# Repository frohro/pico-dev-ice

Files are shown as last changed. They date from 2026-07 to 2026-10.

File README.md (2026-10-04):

# <span style="text-transform: none;">The Pico Dev-iCE 📡</span>
**DSP Educational Vehicle & iCE40 Mixed-Signal Laboratory**

## 📌 Overview
The **Pico Dev-iCE** is a low-cost, high-performance "Lab-in-a-Box." It combines the high-speed programmable logic of a **Lattice iCE40UP5K FPGA** with the flexible C/MicroPython ecosystem of a **Raspberry Pi Pico (YD-RP2040 with 16MB Flash)**. 

Designed specifically as an educational platform, it abandons "black box" RF chips in favor of discrete, observable analog blocks. Students can physically probe the RF signal path, design their own LC filters on pluggable sandboxes, and write Verilog to perform Direct Digital Conversion (DDC), digital decimation, and hardware I2S audio routing.

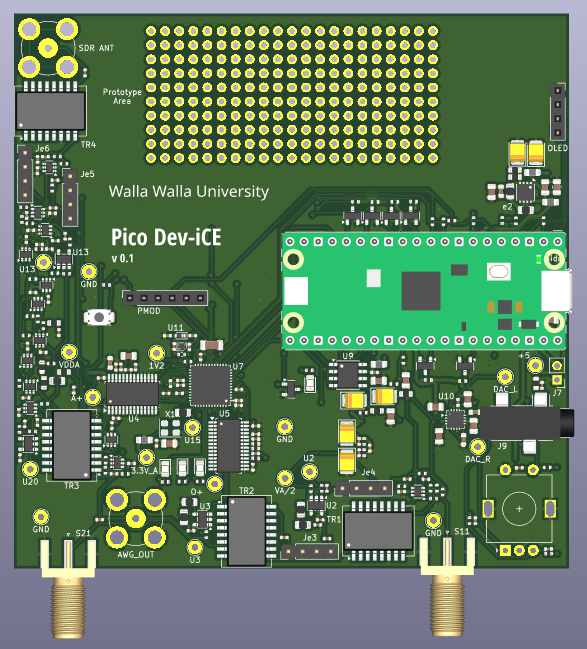
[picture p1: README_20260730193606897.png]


Here is a video of the SDR receiving on 20 meters.(https://youtu.be/qYo4EEl96wU).
## 🚀 Key Capabilities
* **HF Software Defined Radio (RX/TX):** Full-duplex DDC/DUC transceiver covering 0 - 15.36 MHz (1st Nyquist) with Super-Nyquist capabilities up to 30+ MHz.
* **Vector Network Analyzer (VNA):** Built-in Return Loss Bridge (RLB) for S11 (reflection) antenna tuning, and Port-to-Port S21 (transmission) filter characterization.
* **Arbitrary Waveform Generator (AWG):** Dedicated DC-coupled and AC-coupled SMA outputs for 30 MSPS generic signal generation.
* **Real-Time Spectrum Analyzer:** Visualize the entire 15 MHz HF spectrum simultaneously via FPGA-accelerated FFTs.
* **Standalone Operation:** Onboard Audio DAC/Headphone amp and rotary encoder support allows the board to operate as a standalone radio without a PC.

---

## 🧠 Hardware Architecture

### Processing Core
* **Microcontroller:** YD-RP2040 / Pico 2 socket. Handles AGC math, user interface, USB communications, and slow-state hardware toggles. The massive internal Flash (up to 16MB) stores the FPGA bitstream and programs the FPGA directly on every boot, eliminating the need for an external FPGA flash chip.
* **FPGA:** Lattice iCE40UP5K (SG48). Handles high-speed 30.72 MHz DSP, NCO generation, CIC decimation/interpolation, and I2S master clocking.
* **Control Bus:** The Pico uses its high-speed `SPI0` bus to dual-role: it blasts the bitstream into the FPGA's internal CRAM on boot, and then seamlessly transitions to sending runtime DSP commands to the user's Verilog over the exact same 4 wires.

### Clocking & DSP Math
* **Master Clock:** A clean 30.720 MHz CMOS oscillator drives the FPGA.
* **The Magic of 30.72 MHz:** The FPGA decimates the 30.72 MSPS ADC data by exactly $R=640$ to yield a mathematically perfect **48.000 kHz** baseband I/Q audio stream over I2S to the Pico. 
* **Process Gain:** The 640x decimation provides ~ 28 dB of digital processing gain, turning the raw 8-bit ADC into a highly sensitive 12.6-bit effective receiver!

### The Receive (RX) Path
* **Topology:** `SMA` ➔ `Ethernet Isolation/CMC` ➔ `Band Sandbox` ➔ `T/R Switch` ➔ `LNA 1` ➔ `PGA (5/10dB)` ➔ `LNA 2` ➔ `ADC`.
* **Amplifiers:** Uses discrete high-speed op-amps wired as AC-coupled inverting amplifiers. 
* **Programmable Gain:** A Digital Step Attenuator (DSA) built from CMOS switches and precision T-networks, providing 0 to 55 dB of gain control in 5 dB steps. LNA 1 and LNA 2 are both bypassable to prevent clipping on massive signals.
* **ADC (MS9280):** 8-bit, 32 MSPS. Driven by an RF balun into True Differential Mode with a 4.5V analog supply, yielding a massive 4.0V peak-to-peak input span for maximum dynamic range.

### The Transmit (TX) Path
* **Topology:** `DAC` ➔ `Passive I-V` ➔ `Ethernet Transformer` ➔ `TX Switch` ➔ `Recon Sandbox` ➔ `TX Op-Amp (+12dB)` ➔ `T/R Switch` ➔ `SMA`.
* **DAC (MS9708):** 8-bit, 32 MSPS Current-Steering DAC.
* Passive 50Ω resistors and an Ethernet transformer gracefully map the DAC's strict output compliance limits into a clean 1.0V p-p RF signal, which is then amplified to drive a 50-ohm antenna.

### Power Domains (Strict Isolation)
To achieve commercial-grade noise floors, the noisy Switch-Mode Power Supply (SMPS) of standard Picos is bypassed/isolated. 
* **`+4.5V AVDD`:** Clean LDO powering the RF op-amps, analog switches, and ADC/DAC analog cores.
* **`+3.3V Digital`:** LDO powering the FPGA I/O, Pico, and IC logic.
* **`+3.3V Clean`:** Ferrite bead + LC filtered rail strictly for the 30.72 MHz oscillator to eliminate phase-noise/jitter.

---

## 🎛️ Port & Jumper Reference

### Coaxial Connectors
1. **`SDR_ANT`(BNC):** Main Transceiver Port (Transformer isolated, AC-Coupled).
2. **`SII` (SMA):** Device Under Test port for S11/VSWR Antenna measurements. Connects to the internal Return Loss Bridge.
3. **`AWG_OUT` (BNC):** Direct DC-coupled output (0V to +4V) from the DAC. Perfect for baseband signal generation.
4. **`S21` (SMA):** AC-coupled output for S21 Filter sweeps and RF signal generation. Protects the op-amp from DC-shorted filters.

### Filter Sandboxes (Plug-and-Play)
The board features `IN-GND-GND-OUT` 0.1" sockets for inserting custom filter daughterboards. 
* **Band Sandbox:** Shared by both RX and TX (pre-T/R switch). Students calculate and test bandpass filters here.
* **TX Pre-Sandbox:** Placed before the TX amplifier. Used for mild Nyquist reconstruction filters or super-Nyquist image-selection filters.

---

## 🛠️ Software & HDL Notes

* **Level Shifters (Logic Inversion):** The 4.5V analog switches are controlled by 3.3V GPIOs via 2N7002 N-Channel MOSFETs. **Note:** This results in a logic inversion. Writing `0` to the pin in MicroPython = Switch HIGH (Max Gain / Default Path). Writing `1` = Switch LOW (Attenuated / VNA / TX Path).
* **FPGA Boot & SPI0 Bus:** 
    *   The external FPGA Flash chip was removed to simplify the architecture. The Pico boots the FPGA directly by blasting the bitstream into CRAM using its Hardware `SPI0` block. 
    *   Because the Pico drives the bus, the net names match the Pico's hardware roles: `SPI0_TX` (MOSI) is data entering the FPGA, and `SPI0_RX` (MISO) is data leaving the FPGA. 
    *   **Runtime:** Once booted, the Pico reuses the exact same `SPI0` bus and `ICE_SSN` Chip Select pin to send DSP commands to the user's Verilog.
* **ADC OTR:** The MS9280 "Out of Range" (Clipping) pin pulses for only 32ns. The FPGA catches this, stretches the pulse, and triggers a hardware interrupt on the Pico to engage the AGC.

The ten-week, verification-first HDL course sequence is documented in
[`DDC_SDR_Lab_Plan.md`](DDC_SDR_Lab_Plan.md).

---

## 📍 Hardware Pinout Reference

### 1. Microcontroller (Raspberry Pi Pico) Pinout
*This map defines the interface for the software team handling AGC, VNA sweeps, user interface, and I2S audio routing.*

| Pico GPIO | Net Name | Function | Direction | Notes |
| :--- | :--- | :--- | :--- | :--- |
| **GPIO 0** | `FPGA_INT` | FPGA Hardware Interrupt | Input | Catches stretched ADC Out-Of-Range (OTR) pulses |
| **GPIO 1** | `PMOD_3` | PMOD / GPIO Jump | I/O | Connected via series resistor R32 to PMOD_3 |
| **GPIO 2** | `SDA` | I2C Data | In/Out | I2C bus for the OLED Display |
| **GPIO 3** | `SCL` | I2C Clock | Output | I2C bus for the OLED Display |
| **GPIO 4** | `SPI0_RX` | SPI0 MISO | Input | Data entering Pico from FPGA (via series resistor R33) |
| **GPIO 5** | `ICE_SSN` | SPI0 CSn (FPGA CS) | Output | Hardware SPI0 Chip Select (Boot & Runtime) |
| **GPIO 6** | `SPI0_CLK` | SPI0 SCK | Output | SPI Clock for Boot and Runtime (via series resistor R34) |
| **GPIO 7** | `SPI0_TX` | SPI0 MOSI | Output | Data leaving Pico to FPGA (via series resistor R35) |
| **GPIO 8** | `PGA0` | 5 dB Attenuator | Output | Logic 1 = Attenuator Active (LOW at switch) |
| **GPIO 9** | `PGA1` | 10 dB Attenuator | Output | Logic 1 = Attenuator Active (LOW at switch) |
| **GPIO 10** | `PGA2` | LNA 2 Bypass | Output | Logic 1 = LNA Bypassed (LOW at switch) |
| **GPIO 11** | `PGA3` | LNA 1 Bypass | Output | Logic 1 = LNA Bypassed (LOW at switch) |
| **GPIO 12** | `BAND_SW` | Band Filter Sandbox | Output | Toggles sandbox selection switch |
| **GPIO 13** | `TX_DATA` | I2S TX Data | Output | Full-Duplex Baseband Audio TO the FPGA |
| **GPIO 14** | `RX_DATA` | I2S RX Data | Input | Full-Duplex Baseband Audio FROM the FPGA |
| **GPIO 15** | `BCK` | I2S Bit Clock | Input | Clocks generated by FPGA (I2S Master) |
| **GPIO 16** | `WS` | I2S Word Select (L/R) | Input | Clocks generated by FPGA (I2S Master) |
| **GPIO 17** | `AF_DAC_DATA` | Audio DAC Data | Output | I2S out to standalone headphone amp |
| **GPIO 18** | `AF_DAC_MCLK` | Audio DAC Master | Output | I2S out to standalone headphone amp |
| **GPIO 19** | `AF_DAC_SCLK` | Audio DAC Clock | Output | I2S out to standalone headphone amp |
| **GPIO 20** | `AF_DAC_LRCK` | Audio DAC L/R | Output | I2S out to standalone headphone amp |
| **GPIO 21** | `ICE_DONE` | FPGA Boot Status | Input | Goes HIGH when FPGA is running and lights White LED |
| **GPIO 22** | `~ICE_RST` | FPGA Reset | Output | Pull LOW to hold FPGA in reset |
| **GPIO 26** | `REF` | Front-End RF Mux | Output | **0 = SDR RF Antenna RX**, 1 = VNA Input |
| **GPIO 27** | *(Optional)* | PMOD / GPIO Jump | I/O | Jumper JP3 maps to PMOD_2 |
| **GPIO 28** | `~T/R` | Transmit/Receive Sw | Output | **1 = RX Mode** (Antenna -> LNA), 0 = TX Mode |

### 2. FPGA (Lattice iCE40UP5K-SG48) Pinout
*This map defines the interface for the digital design team writing Verilog and the `.pcf` constraints file.*

| Pin # | Lattice Name | Net Name | Function / Connection |
| :---: | :--- | :--- | :--- |
| **37** | `IOT_45a_G1` | `CLK` | **30.72 MHz Master Clock IN** (From Oscillator) |
| **23** | `IOT_37a` | `ADC_CLK` | ADC Clock OUT (To MS9280 via 22Ω resistor) |
| **6** | `IOB_13b` | `DAC_CLK` | DAC Clock OUT (To MS9708) |
| **25** | `IOT_36b` | `D0` | ADC Data Bit 0 (LSB) |
| **26** | `IOT_39a` | `D1` | ADC Data Bit 1 |
| **27** | `IOT_38b` | `D2` | ADC Data Bit 2 |
| **28** | `IOT_41a` | `D3` | ADC Data Bit 3 |
| **31** | `IOT_42b` | `D4` | ADC Data Bit 4 |
| **32** | `IOT_43a` | `D5` | ADC Data Bit 5 |
| **34** | `IOT_44b` | `D6` | ADC Data Bit 6 |
| **35** | `IOT_46b_G0` | `D7` | ADC Data Bit 7 (MSB) |
| **36** | `IOT_48b` | `OTR` | ADC Out of Range (Clipping Flag) |
| **4** | `IOB_8a` | `DB0` | DAC Data Bit 0 (LSB) |
| **3** | `IOB_9b` | `DB1` | DAC Data Bit 1 |
| **2** | `IOB_6a` | `DB2` | DAC Data Bit 2 |
| **48** | `IOB_4a` | `DB3` | DAC Data Bit 3 |
| **47** | `IOB_2a` | `DB4` | DAC Data Bit 4 |
| **46** | `IOB_0a` | `DB5` | DAC Data Bit 5 |
| **45** | `IOB_5b` | `DB6` | DAC Data Bit 6 |
| **44** | `IOB_3b_G6` | `DB7` | DAC Data Bit 7 (MSB) |
| **14** | `IOB_32a_SPI_SO` | `SPI0_RX` | SPI MISO (Data *to* Pico during runtime) |
| **17** | `IOB_33b_SPI_SI` | `SPI0_TX` | SPI MOSI (Data *from* Pico during runtime) |
| **15** | `IOB_34a_SPI_SCK`| `SPI0_CLK` | SPI Clock IN (From Pico GPIO 6) |
| **16** | `IOB_35b_SPI_SS` | `ICE_SSN` | SPI Chip Select IN (From Pico GPIO 5) |
| **12** | `IOB_22a` | `BCK` | I2S Bit Clock OUT (To Pico GPIO 15) |
| **9** | `IOB_16a` | `WS` | I2S Word Select OUT (To Pico GPIO 16) |
| **11** | `IOB_20a` | `RX_DATA` | I2S Data OUT (SDR audio to Pico GPIO 14) |
| **10** | `IOB_18a` | `TX_DATA` | I2S Data IN (Transmit audio from Pico GPIO 13) |
| **13** | `IOB_24a` | `FPGA_INT` | Hardware Interrupt OUT (To Pico GPIO 0) |
| **38** | `IOT_50b` | `ANG_0` | Rotary Encoder / Tuning Knob A |
| **42** | `IOT_51a` | `ANG_1` | Rotary Encoder / Tuning Knob B |
| **43** | `IOT_49a` | `ANG_2` | Rotary Encoder / Tuning Knob Switch |
| **21** | `IOB_23b` | `PMOD_0` | PMOD Header Pin 1 |
| **19** | `IOB_29b` | `PMOD_1` | PMOD Header Pin 2 |
| **18** | `IOB_31b` | `PMOD_2` | PMOD Header Pin 3 |
| **20** | `IOB_25b_G3` | `PMOD_3` | PMOD Header Pin 4 |
| **39** | `RGB0` | `RED` | Open-Drain LED Driver (Active-Low: 0=ON, pulses on ADC OTR clipping) |
| **40** | `RGB1` | `YELLOW` | Open-Drain LED Driver (Active-Low: 0=ON, pulses on SPI tuning activity) |
| **41** | `RGB2` | `GREEN` | Open-Drain LED Driver (Active-Low: 0=ON, steady ON when un-reset) |
| **7** | `CDONE` | `ICE_DONE` | *Hardware Boot / Status Out* |
| **8** | `~CRESET` | `~ICE_RST` | *Hardware Boot / Reset In* |

## Pico SDK Bring-Up

The SDK port is under `Software/pico-ice-sdk`. It uses the checked-in Pico SDK
(currently 2.2.0). The general SDK examples use the TinyUSB revision bundled by
that SDK. The DDC firmware below uses a newer TinyUSB checkout because it needs
the UAC1 descriptor definitions that are not present in the bundled revision.

The smallest board-specific firmware example programs the FPGA's volatile CRAM directly from the RP2040:

```sh
cmake -S Software/pico-ice-sdk/examples/rp2_dev_ice_blinky \
    -B Software/pico-ice-sdk/examples/rp2_dev_ice_blinky/build \
    -DPICO_BOARD=pico_dev_ice -DPICO_NO_PICOTOOL=1
cmake --build Software/pico-ice-sdk/examples/rp2_dev_ice_blinky/build
```

The generated UF2 is RP2040 firmware that contains the FPGA bitstream. The Dev-iCE has no external FPGA configuration flash, so the board port excludes the external-flash and TinyUF2 FPGA-storage paths. SPI0 GPIO 6 is the CRAM transfer clock and GPIO 7 carries configuration data; normal FPGA operation uses the separate external 30.720 MHz oscillator, not a Pico-generated clock on GPIO 27.

## DDC SDR Firmware

The first Dev-iCE SDR application is in
[`Software/ddc_sdr_firmware`](Software/ddc_sdr_firmware). It replaces the
earlier Si5351a, Tayloe detector, and PCM1808 path with FPGA-generated DDC I/Q data received as
PCM1808-compatible I2S. The Pico firmware:

* programs the FPGA's volatile CRAM over SPI0;
* reuses SPI0 for runtime frequency and sample-rate commands;
* captures FPGA I2S with DMA; and
* exposes stereo 24-bit UAC1 audio at 48 kHz and 96 kHz, CDC control, and a
    DFU interface.

The DDC application requires a TinyUSB checkout with both `src/tusb.h` and
`hw/bsp/rp2040`. A current checkout at `$HOME/tinyusb` is detected
automatically, or it can be selected explicitly:

```sh
cmake -S Software/ddc_sdr_firmware -B Software/ddc_sdr_firmware/build \
        -DPICO_TINYUSB_PATH="$HOME/tinyusb" \
        -DPICO_BOARD=pico_dev_ice \
        -DPICO_NO_PICOTOOL=1
cmake --build Software/ddc_sdr_firmware/build -j2
```

The Pico firmware keeps FPGA deployment easy to choose: `FPGA_BOOT_MODE=DFU`
waits for a development bitstream from `dfu-util`, while
`FPGA_BOOT_MODE=STORED` loads an image embedded in the Pico firmware at boot.
Two stored transceiver profiles can be included with
`FPGA_RX_BITSTREAM_BIN` and `FPGA_TX_BITSTREAM_BIN`, with
`FPGA_DEFAULT_IMAGE` selecting the boot profile and `FPGA,LOAD,RX` or
`FPGA,LOAD,TX` selecting one between sessions. The full commands and build
examples are in [`Software/ddc_sdr_firmware/README.md`](Software/ddc_sdr_firmware/README.md).

These profile loads are not a VNA sweep mechanism. A VNA needs a single
coherent FPGA design containing the stimulus, reference, receive, and
measurement paths for the complete sweep. Select a persistent VNA-capable
image before a measurement, or implement those paths in one integrated image;
do not reconfigure between sweep points.

For development, compile an FPGA bitstream with Yosys, nextpnr-ice40, and
icepack, then load it without reflashing the Pico:

```sh
python3 Software/ddc_sdr_firmware/tools/dfu_fpga.py /path/to/ddc_sdr.bin
```

Stop the SDR++ or Quisk audio stream before starting DFU. The helper prepares
the shared SPI0 bus, sends the packed bitstream through `dfu-util`, and lets the
Pico restore the runtime FPGA state afterward. Do not reset the Pico after a
DFU-only update: FPGA CRAM is volatile and a reset clears the loaded design.

For the complete pinout, SPI protocol, CDC commands, build options, and DFU
sequence, see [`Software/ddc_sdr_firmware/README.md`](Software/ddc_sdr_firmware/README.md).

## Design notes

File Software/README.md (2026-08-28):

# Pico Dev-iCE Software & DSP Architecture

This document provides a comprehensive technical reference for the **Pico Dev-iCE Software-Defined Radio (SDR)** system, detailing the mathematical foundations of the Digital Down-Conversion (DDC) pipeline, the Programmable Gain Amplifier (PGA) control and Automatic Gain Control (AGC) algorithms, the system block diagrams, and the software repository directory layout.

---

## Table of Contents
1. [System Architecture & Block Diagram](#1-system-architecture--block-diagram)
2. [Mathematical Foundations of the DSP Pipeline](#2-mathematical-foundations-of-the-dsp-pipeline)
   - [2.1 RF Sampling & Offset-Binary Conversion](#21-rf-sampling--offset-binary-conversion)
   - [2.2 DC Auto-Zero Offset Correction](#22-dc-auto-zero-offset-correction)
   - [2.3 Numerically Controlled Oscillator (NCO)](#23-numerically-controlled-oscillator-nco)
   - [2.4 Complex Quadrature Downconversion (Mixer)](#24-complex-quadrature-downconversion-mixer)
   - [2.5 Cascaded Integrator-Comb (CIC) Decimating Filter](#25-cascaded-integrator-comb-cic-decimating-filter)
   - [2.6 Output Scaling & Bit Growth Analysis](#26-output-scaling--bit-growth-analysis)
   - [2.7 Dual-Rate FIR Passband Droop Equalization](#27-dual-rate-fir-passband-droop-equalization)
   - [2.8 Dual-Rate I2S Baseband Transmission](#28-dual-rate-i2s-baseband-transmission)
3. [PGA Gain Control & AGC Algorithm](#3-pga-gain-control--agc-algorithm)
   - [3.1 Hardware PGA Architecture](#31-hardware-pga-architecture)
   - [3.2 Manual Gain Control & OpenHPSDR Protocol 1 Mapping](#32-manual-gain-control--openhpsdr-protocol-1-mapping)
   - [3.3 Fast-Attack / Timed-Decay Overload AGC](#33-fast-attack--timed-decay-overload-agc)
4. [Software Directory Overview](#4-software-directory-overview)
   - [4.1 ddc_sdr_firmware](#41-ddc_sdr_firmware)
   - [4.2 ddc_sdr_firmware_usb_working](#42-ddc_sdr_firmware_usb_working)
   - [4.3 Soapy-Dev-iCE](#43-soapy-dev-ice)
   - [4.4 Pico Dev-iCE MicroPython](#44-pico-dev-ice-micropython)
   - [4.5 pico-ice-sdk](#45-pico-ice-sdk)

---

## 1. System Architecture & Block Diagram

The Pico Dev-iCE SDR partitions signal processing between a high-speed **Lattice iCE40UP5K FPGA** (performing real-time Digital Down-Conversion, dual-rate CIC decimation, and FIR passband droop compensation at 30.72 MHz) and a **Raspberry Pi RP2040 / Pico W MCU** (handling DMA sample acquisition, USB Audio streaming, Wi-Fi OpenHPSDR Protocol 1 streaming, AGC supervision, and Command & Control).
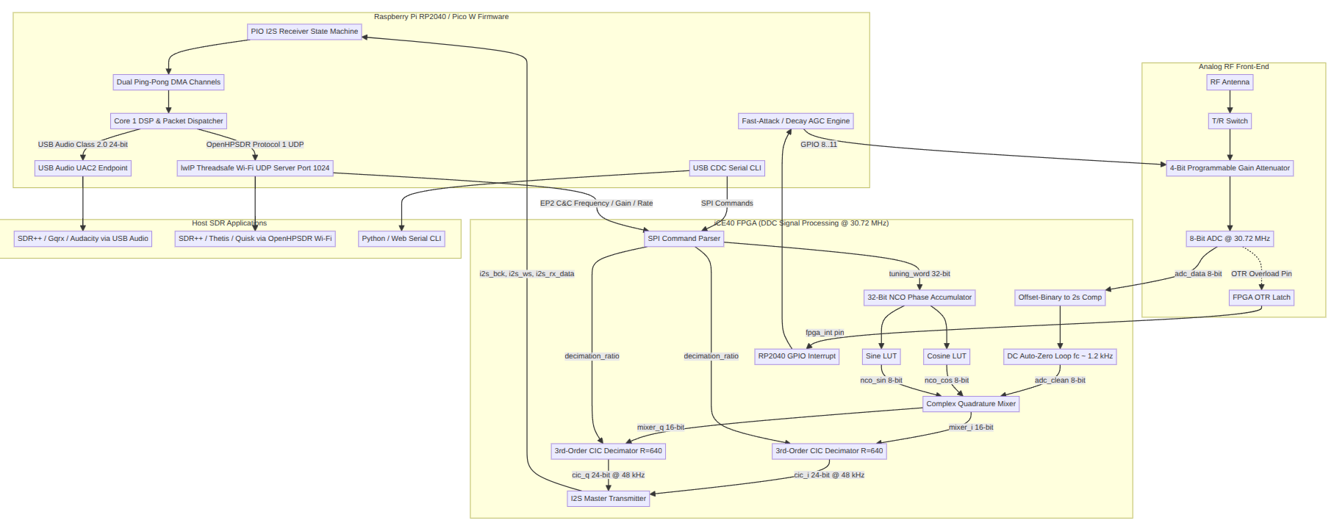
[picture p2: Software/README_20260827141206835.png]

```mermaid
graph TD
    subgraph Analog_RF_FrontEnd ["Analog RF Front-End"]
        ANT[RF Antenna] --> TR[T/R Switch]
        TR --> PGA[4-Bit Programmable Gain Attenuator]
        PGA --> ADC[8-Bit ADC @ 30.72 MHz]
        ADC -.->|OTR Overload Pin| FPGA_INT[FPGA OTR Latch]
    end

    subgraph FPGA_DSP ["iCE40 FPGA (DDC Signal Processing @ 30.72 MHz)"]
        ADC -->|adc_data 8-bit| O2C[Offset-Binary to 2s Comp]
        O2C --> DCZ[DC Auto-Zero Loop fc ~ 1.2 kHz]
        DCZ -->|adc_clean 8-bit| MIX[Complex Quadrature Mixer]
        
        NCO_GEN[32-Bit NCO Phase Accumulator] --> SIN_LUT[Sine LUT]
        NCO_GEN --> COS_LUT[Cosine LUT]
        COS_LUT -->|nco_cos 8-bit| MIX
        SIN_LUT -->|nco_sin 8-bit| MIX

        MIX -->|mixer_i 16-bit| CIC_I[Dual-Rate CIC Decimator R=640/320]
        MIX -->|mixer_q 16-bit| CIC_Q[Dual-Rate CIC Decimator R=640/320]

        CIC_I -->|cic_i 24-bit| FIR_I[5-Tap Symmetric FIR Compensator]
        CIC_Q -->|cic_q 24-bit| FIR_Q[5-Tap Symmetric FIR Compensator]

        FIR_I -->|audio_i 24-bit @ 48k/96k| I2S_TX[Dual-Rate I2S Master Transmitter]
        FIR_Q -->|audio_q 24-bit @ 48k/96k| I2S_TX
        
        SPI_SLV[SPI Command Parser] -->|tuning_word 32-bit| NCO_GEN
        SPI_SLV -->|CMD_SET_SAMPLE_RATE 0x02| CIC_I
        SPI_SLV -->|CMD_SET_SAMPLE_RATE 0x02| CIC_Q
        SPI_SLV -->|rate_select| I2S_TX
        FPGA_INT -->|fpga_int pin| MCU_INT[RP2040 GPIO Interrupt]
    end

    subgraph MCU_RP2040 ["Raspberry Pi RP2040 / Pico W Firmware"]
        I2S_TX -->|i2s_bck, i2s_ws, i2s_rx_data| PIO_RX[PIO I2S Receiver State Machine]
        PIO_RX --> DMA[Dual Ping-Pong DMA Channels]
        DMA --> CORE1[Core 1 DSP & Packet Dispatcher]
        
        CORE1 -->|USB Audio Class 2.0 24-bit| USB_EP[USB Audio UAC2 Endpoint]
        CORE1 -->|OpenHPSDR Protocol 1 UDP| WIFI_LWIP[lwIP Threadsafe Wi-Fi UDP Server Port 1024]
        
        AGC_CTRL[Fast-Attack / Decay AGC Engine] -->|GPIO 8..11| PGA
        MCU_INT --> AGC_CTRL
        CDC_CLI[USB CDC Serial CLI] -->|SPI Commands| SPI_SLV
        WIFI_LWIP -->|EP2 C&C Frequency / Gain / Rate| SPI_SLV
    end

    subgraph Host_Software ["Host SDR Applications"]
        USB_EP --> SDRPP_U[SDR++ / Gqrx / Audacity via USB Audio]
        WIFI_LWIP --> SDRPP_W[SDR++ / Thetis / Quisk via OpenHPSDR Wi-Fi]
        CDC_CLI --> SERIAL_APP[Python / Web Serial CLI]
    end
```

---

## 2. Mathematical Foundations of the DSP Pipeline

### 2.1 RF Sampling & Offset-Binary Conversion
The analog RF input is digitized by an 8-bit Flash ADC clocked at $f_s = 30.720\text{ MHz}$. The ADC produces unsigned offset-binary samples $x_{raw}[n] \in [0, 255]$.

To convert unsigned offset-binary to 8-bit signed two’s complement $x_{signed}[n] \in [-128, 127]$, the MSB is inverted:

$$x_{signed}[n] = x_{raw}[n] - 128 = \left( \sim x_{raw}[7] \right) \mathbin{\Vert} x_{raw}[6:0]$$

---

### 2.2 DC Auto-Zero Offset Correction
ADC hardware imperfection and local board coupling introduce a static DC offset bias $V_{DC}$. If passed uncorrected into the mixer, $V_{DC} \cdot \cos(\omega_{lo} n)$ produces a massive spurious tone directly at the tuned center frequency ($0\text{ Hz}$ IF).

An autonomous digital tracking loop dynamically integrates and subtracts this DC bias before mixing:

$$\text{dc\_acc}[n] = \text{dc\_acc}[n-1] + x_{signed}[n] - \text{sign\_ext}\left(\text{dc\_acc}[n-1][23:12]\right)$$

$$x_{clean}[n] = \text{saturate}_{[-128, 127]}\left( x_{signed}[n] - \text{dc\_acc}[n][23:12] \right)$$

This creates a high-pass notch with a cutoff frequency:

$$f_{c} \approx \frac{f_s}{2^{12} \cdot 2\pi} = \frac{30.720\text{ MHz}}{4096 \cdot 2\pi} \approx 1.193\text{ kHz}$$

This eliminates center-frequency LO carrier spikes without degrading passband signals.

---

### 2.3 Numerically Controlled Oscillator (NCO)
The NCO implements a 32-bit phase accumulator clocked at $f_{clk} = 30.720\text{ MHz}$. For a target RF center frequency $f_{tune}$, the RP2040 calculates the 32-bit integer tuning word $M$:

$$M = \operatorname{round}\left( \frac{f_{tune}}{f_{clk}} \cdot 2^{32} \right) = \operatorname{round}\left( \frac{f_{tune}}{30{,}720{,}000} \cdot 4{,}294{,}967{,}296 \right)$$

The phase accumulator updates on every clock cycle:

$$\theta[n] = \left( \theta[n-1] + M \right) \pmod{2^{32}}$$

The frequency resolution $\Delta f$ is:

$$\Delta f = \frac{f_{clk}}{2^{32}} = \frac{30.720\text{ MHz}}{4{,}294{,}967{,}296} \approx 0.007153\text{ Hz}$$

The top 8 bits $\theta[n][31:24]$ index 256-word quarter-wave trigonometric lookup tables to yield 8-bit signed quadrature LO reference signals:

$$I_{lo}[n] = \cos\left( \frac{2\pi \cdot \theta[n]}{2^{32}} \right), \quad Q_{lo}[n] = \sin\left( \frac{2\pi \cdot \theta[n]}{2^{32}} \right)$$

---

### 2.4 Complex Quadrature Downconversion (Mixer)
The clean real RF input signal $x_{clean}[n]$ is multiplied by the quadrature LO signals $I_{lo}[n]$ and $Q_{lo}[n]$ to produce in-phase ($I$) and quadrature ($Q$) products:

$$I_{mix}[n] = x_{clean}[n] \cdot I_{lo}[n] = x_{clean}[n] \cos(\omega_{lo} n)$$

$$Q_{mix}[n] = x_{clean}[n] \cdot Q_{lo}[n] = x_{clean}[n] \sin(\omega_{lo} n)$$

For an arbitrary narrowband input signal $x(t) = A(t) \cos(\omega_{rf} t + \phi(t))$ where $\omega_{rf} = \omega_{lo} + \omega_{if}$:

$$I_{mix}(t) = \frac{A(t)}{2}\left[ \cos(\omega_{if} t + \phi(t)) + \cos((2\omega_{lo} + \omega_{if})t + \phi(t)) \right]$$

$$Q_{mix}(t) = \frac{A(t)}{2}\left[ -\sin(\omega_{if} t + \phi(t)) + \sin((2\omega_{lo} + \omega_{if})t + \phi(t)) \right]$$

The complex analytic signal at the mixer output is:

$$z_{mix}(t) = I_{mix}(t) + j Q_{mix}(t) = \frac{A(t)}{2} e^{-j(\omega_{if} t + \phi(t))} + \frac{A(t)}{2} e^{j((2\omega_{lo} + \omega_{if})t + \phi(t))}$$

The high-frequency $2\omega_{lo}$ sum term is removed by the subsequent decimation filter, isolating the baseband spectrum $e^{-j\omega_{if} t}$.

---

### 2.5 Cascaded Integrator-Comb (CIC) Decimating Filter
Decimation and low-pass anti-aliasing filtering are implemented using a **3-Stage Cascaded Integrator-Comb (CIC) filter** (Hogenauer, 1981) with differential delay $M=1$ and decimation ratio $R = 640$ (for $48\text{ kHz}$) or $R = 320$ (for $96\text{ kHz}$).

The system transfer function in the $z$-domain is:

$$H(z) = \left( \frac{1 - z^{-R M}}{1 - z^{-1}} \right)^N = \left( \sum_{k=0}^{R M - 1} z^{-k} \right)^N, \quad N=3, \; M=1$$

The discrete-time frequency response is:

$$|H(f)| = \left| \frac{\sin\left(\pi \frac{R M f}{f_s}\right)}{\sin\left(\pi \frac{f}{f_s}\right)} \right|^N$$

#### Filter Structure:
1. **3 Integrator Stages** clocked at full ADC rate $f_s = 30.72\text{ MHz}$:
   $$I_1[n] = I_1[n-1] + x[n]$$
   $$I_2[n] = I_2[n-1] + I_1[n]$$
   $$I_3[n] = I_3[n-1] + I_2[n]$$
2. **Decimator $\downarrow R$**: Samples $I_3[n]$ every $R=640$ clocks ($f_{out} = 48\text{ kHz}$).
3. **3 Comb Stages** clocked at decimated rate $f_{out}$:
   $$C_1[m] = I_3[m] - I_3[m-1]$$
   $$C_2[m] = C_1[m] - C_1[m-1]$$
   $$C_3[m] = C_2[m] - C_2[m-1]$$

---

### 2.6 Output Scaling & Bit Growth Analysis

#### DC Gain:
$$G = (R \cdot M)^N = 640^3 = 262{,}144{,}000 \approx 2^{27.966}$$

#### Maximum Bit Growth ($B_{growth}$):
$$B_{growth} = \lceil N \log_2(R \cdot M) \rceil = \lceil 3 \log_2(640) \rceil = \lceil 27.966 \rceil = 28\text{ bits}$$

#### Register Sizing:
With a 16-bit signed mixer input ($B_{in} = 16$), the internal accumulator width required to prevent mathematical overflow (by two’s complement wrap-around invariance) is:

$$B_{internal} = B_{in} + B_{growth} = 16 + 28 = 44\text{ bits}$$

#### Dynamic Range Slicing:
- Theoretical peak signed input: $|x_{in}| = 127 \times 128 = 16{,}256 \approx 2^{13.989}$
- Peak theoretical output: $16{,}256 \times 640^3 = 4.262 \times 10^{12} \approx 2^{41.95}$
- Bits $[43:42]$ are redundant sign-extension bits.
- By extracting bits **$[41:18]$** (24 bits total), the filter yields maximum 24-bit dynamic range with **$+12\text{ dB}$ higher sensitivity** while mathematically guaranteeing zero clipping on full-scale sinusoidal RF inputs.

---

### 2.7 Dual-Rate FIR Passband Droop Equalization

While the 3-stage CIC decimator provides high stopband attenuation, its passband exhibits severe $\text{sinc}^3$ droop:
- At $48\text{ kHz}$ ($R=640$), the response droops by **$-7.92\text{ dB}$ at $20\text{ kHz}$** ($0.416 F_s$).
- At $96\text{ kHz}$ ($R=320$), the response droops by **$-7.92\text{ dB}$ at $40\text{ kHz}$** ($0.416 F_s$).

Because normalized frequency $\omega = 2\pi f / F_s$ is identical at both sample rates ($F_s \cdot R = F_{\text{clk}} = 30.72\text{ MHz}$), the exact same FIR compensator flattens both 48 kHz and 96 kHz rates.

#### Minimalist 5-Tap Folded FIR Architecture:
A 5-tap symmetric linear-phase FIR filter ($h_0, h_1, h_2, h_1, h_0$) flattens the response to **$\pm 0.48\text{ dB}$ ($0.96\text{ dB}$ total ripple $\le 1.0\text{ dB}$)**:

$$H_{\text{FIR}}(z) = h_0 + h_1 z^{-1} + h_2 z^{-2} + h_1 z^{-3} + h_0 z^{-4}$$

#### Signed 16-Bit Q2.14 Fixed-Point Sizing:
- $h_0 = h_4 = +0.100302 \times 16384 \approx \mathbf{+1643}$ (`16'sh066B`)
- $h_1 = h_3 = -0.389698 \times 16384 \approx \mathbf{-6385}$ (`16'shE70F`)
- $h_2 = +1.578857 \times 16384 \approx \mathbf{+25868}$ (`16'sh650C`) (Center tap)
- $\sum h_i = 1643 + 1643 - 6385 - 6385 + 25868 = \mathbf{16384} = 2^{14} \implies \mathbf{1.000000}$ **Exact DC Gain**.

#### Dual-Rate Gain Slicing:
- **48 kHz Mode ($R=640$):** Slices bits `[41:18]` (DC gain $= 640^3 / 2^{18} = 1000$).
- **96 kHz Mode ($R=320$):** Slices bits `[38:15]` (DC gain $= 320^3 / 2^{15} = 1000$).
- Dynamic 3-bit downward shift equalizes output volume across sample rate changes with zero multiplier logic.

---

### 2.8 Dual-Rate I2S Baseband Transmission
The compensated 24-bit $I$ and $Q$ samples are transmitted over an I2S serial link in standard Philips framing:
- **48 kHz Mode:** Bit Clock (`i2s_bck`) $= 3.072\text{ MHz}$ ($64 \times 48\text{ kHz}$), Word Select (`i2s_ws`) $= 48.0\text{ kHz}$.
- **96 kHz Mode:** Bit Clock (`i2s_bck`) $= 6.144\text{ MHz}$ ($64 \times 96\text{ kHz}$), Word Select (`i2s_ws`) $= 96.0\text{ kHz}$.
  - $\text{WS} = 0$ (Low): Left Channel = $I$ (In-phase sample)
  - $\text{WS} = 1$ (High): Right Channel = $Q$ (Quadrature sample)
- **Data (`i2s_rx_data`)**: 24-bit signed MSB-first, left-aligned in a 32-bit frame.

The RP2040 PIO state machine acts as an I2S slave, capturing 32 bits into the RX FIFO on each half-period of WS and populating memory buffers with alternating $(I, Q)$ pairs.

---

## 3. PGA Gain Control & AGC Algorithm

### 3.1 Hardware PGA Architecture
The analog front-end includes a 4-bit digitally controlled Programmable Gain Attenuator/Amplifier driven by RP2040 GPIOs $8, 9, 10, 11$ (`DDC_PGA_GPIO_BASE = 8`):

$$\text{PGA Code} \in [0x0, 0xF] \quad (0 \dots 15)$$

| PGA Code | Binary (`GPIO[11:8]`) | Nominal Attenuation | Front-End Net Gain | Mode / Typical Use |
|:---:|:---:|:---:|:---:|:---|
| **0x0** | `0000` | $0\text{ dB}$ | $+40\text{ dB}$ | Maximum Sensitivity / Weak Signal DX |
| **0x1** | `0001` | $-1\text{ dB}$ | $+39\text{ dB}$ | AGC Stage 1 Overload Cut |
| **0x2** | `0010` | $-2\text{ dB}$ | $+38\text{ dB}$ | Fine Manual Step |
| **0x3** | `0011` | $-3\text{ dB}$ | $+37\text{ dB}$ | AGC Stage 2 Overload Cut |
| $\dots$ | $\dots$ | $\dots$ | $\dots$ | Linear $1\text{ dB}$ steps |
| **0xF** | `1111` | $-15\text{ dB}$ | $+25\text{ dB}$ | AGC Maximum Overload Protection / Local Signals |

---

### 3.2 Manual Gain Control & OpenHPSDR Protocol 1 Mapping

Manual gain can be adjusted via CDC CLI or SDR software:
1. **CDC Serial CLI**:
   ```text
   PGA,<0..15>    # Sets attenuation code directly (0 = Max gain, 15 = Min gain)
   ```
2. **OpenHPSDR Protocol 1 / SDR++ Slider Mapping**:
   SDR++ presents an `LNA Gain` slider from $0\text{ dB}$ to $60\text{ dB}$ via Hermes-Lite Register `0x0A` (`HL_REG_RX_LNA`). The firmware maps this continuous slider to the discrete 4-bit hardware attenuation codes:

   $$\text{PGA Code} = 15 - \left\lfloor \frac{\text{Gain}_{SDR++} \times 15}{60} \right\rfloor$$

   - $\text{Gain}_{SDR++} = 60\text{ dB} \implies \text{PGA Code } 0$ (Max gain $+40\text{ dB}$)
   - $\text{Gain}_{SDR++} = 0\text{ dB} \implies \text{PGA Code } 15$ (Max attenuation / $+25\text{ dB}$)

---

### 3.3 Fast-Attack / Timed-Decay Overload AGC

When powerful out-of-band or in-band transmitters saturate the 8-bit ADC, the hardware ADC Out-Of-Range (`adc_otr`) pin fires. The FPGA catches this event, stretches the pulse, and asserts `fpga_int` to the RP2040.

#### AGC State Machine:
```mermaid
stateDiagram-v2
    [*] --> STATE_0dB : System Boot / Target Gain

    STATE_0dB --> STATE_1dB : OTR Interrupt (Fast Attack)
    STATE_1dB --> STATE_3dB : OTR Interrupt (Fast Attack)
    STATE_3dB --> STATE_15dB : OTR Interrupt (Fast Attack)

    STATE_15dB --> STATE_3dB : Quiet Timer > 2000 ms (Decay)
    STATE_3dB --> STATE_1dB : Quiet Timer > 2000 ms (Decay)
    STATE_1dB --> STATE_0dB : Quiet Timer > 2000 ms (Decay)
```

1. **Fast Attack (< 10 µs)**:
   When `fpga_int` triggers an interrupt:
   $$\text{Code}_{next} = \operatorname{StepUp}(\text{Code}_{current}): \quad 0\text{x0} \to 0\text{x1} \to 0\text{x3} \to 0\text{xF}$$
   The attenuator immediately steps to the next safe level, and an SPI command `DDC_FPGA_CMD_CLEAR_OTR` (0x04) clears the FPGA OTR latch.

2. **Hold & Timed Decay ($T_{decay} = 2000\text{ ms}$)**:
   - While `fpga_int` remains active or triggers repeatedly, the quiet timer resets to 0.
   - When the RF overload ceases, the system begins a $2000\text{ ms}$ quiet timer.
   - After $2000\text{ ms}$ with zero OTR pulses, the gain recovers by one step:
     $$\text{Code}_{prev} = \operatorname{StepDown}(\text{Code}_{current}): \quad 0\text{xF} \to 0\text{x3} \to 0\text{x1} \to 0\text{x0}$$
   - This prevents rapid gain pumping / flutter during intermittent high-signal transmissions.

---

## 4. Software Directory Overview

Below is the directory structure of the `Software/` folder and the purpose of each component:

```
Software/
├── README.md                    # DSP mathematics, PGA control, and architecture documentation (this file)
├── ddc_sdr_firmware/            # Primary active RP2040/Pico W production firmware
├── ddc_sdr_firmware_usb_working/ # Historical baseline USB-only firmware snapshot
├── Soapy-Dev-iCE/               # SoapySDR hardware driver module for SDR++/Gqrx
├── Pico Dev-iCE MicroPython/     # MicroPython runtime & hardware peripheral bindings
└── pico-ice-sdk/                # Low-level FPGA flashing & hardware abstraction library
```

---

### 4.1 `ddc_sdr_firmware`
**Active Production Firmware for RP2040 and Pico W.**
- **Dual-Path Streaming**:
  - **USB Audio Class 2.0 (UAC2)**: Isochronous 24-bit stereo audio streaming at 48/96 kHz.
  - **Wi-Fi OpenHPSDR Protocol 1**: Hermes SDR transceiver emulation over threadsafe background lwIP UDP on port 1024.
- **Hardware Bridges**:
  - **PIO I2S Driver (`i2s_rx.pio`)**: Non-blocking DMA-driven stereo receiver.
  - **FPGA CRAM DFU Loader**: Direct flashing and reprogramming of the iCE40 FPGA bitstream across boot and runtime.
  - **SPI Runtime Control**: High-speed frequency tuning, decimation rate switching, and OTR clearing.
- **Overload AGC Engine**: Multi-level fast-attack attenuator stepping with 2-second decay.
- **Full Duplex CDC Serial Interface**: CLI for frequency control, PGA setting, Wi-Fi configuration (`WIFI`, `SCAN`), and system status.

---

### 4.2 `ddc_sdr_firmware_usb_working`
**Reference USB Baseline Firmware.**
- Standalone snapshot of the firmware prior to Wi-Fi integration.
- Useful for minimal-footprint USB deployments or as a test golden reference.

---

### 4.3 `Soapy-Dev-iCE`
**SoapySDR Plugin for Native SDR Ecosystem Integration.**
- C++ hardware module implementing the `SoapySDR::Device` API.
- Enables native plug-and-play support for:
  - **SDR++** (via `soapy_source`)
  - **Gqrx**
  - **CubicSDR**
  - **GNU Radio** (via `gr-soapy` blocks)
- Exposes named gain elements (`PGA`, $0 \dots 15\text{ dB}$), hardware AGC switches, custom sample rates, and streaming channels.

---

### 4.4 `Pico Dev-iCE MicroPython`
**MicroPython Port for Interactive Experimentation.**
- MicroPython firmware build targeting the Pico Dev-iCE platform.
- Provides interactive Python REPL bindings to:
  - Load FPGA bitstreams from flash or filesystem.
  - Configure SPI/I2C registers dynamically.
  - Test custom DSP scripts and control GPIO pins interactively.

---

### 4.5 `pico-ice-sdk`
**Low-Level FPGA & Hardware Abstraction SDK.**
- Underlying C library providing:
  - iCE40 CRAM programming algorithms.
  - SPI flash pass-through programming.
  - Clock generation and RP2040-iCE40 pin mapping definitions.

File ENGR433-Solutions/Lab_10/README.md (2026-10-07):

# Lab 10 Solution: Automatic Gain Control

This solution implements the Pico-side AGC contract for the verified FPGA OTR
interrupt. It uses the existing C firmware rather than a blocking script:

- `agc_control.h` contains the host-testable AGC state machine.
- `main.c` keeps the GPIO interrupt callback short by setting a pending flag.
- The foreground loop advances the PGA state and sends the clear-OTR command.
- A nonblocking millisecond timer decays gain after 2 seconds of quiet.
- Runtime FPGA SPI is explicitly configured to 10 MHz.

The only automatic PGA sequence is:

```text
0x0 -> 0x1 -> 0x3 -> 0xF
```

Each OTR event advances one state and sends exactly:

```text
D5 01 04 04 01 00 00 00
```

At `0xF`, further OTR events remain saturated. When `FPGA_INT` is low for
2,000 ms, the state steps backward through `0x3`, `0x1`, and `0x0`. The timer
is restarted by a new OTR event and never blocks USB, audio, or CDC handling.

## Host tests

Run the AGC state-machine test:

```sh
gcc -std=c11 -Wall -Wextra -Werror \
  -I Software/ddc_sdr_firmware \
  -o /tmp/test_agc_control \
  Software/ddc_sdr_firmware/tools/test_agc_control.c
/tmp/test_agc_control
```

Run the protocol tests, including the exact clear-OTR frame:

```sh
python3 -m unittest \
  Software/ddc_sdr_firmware/tools/test_ddc_protocol.py
```

## Pico firmware build

### Build the Lab 10 FPGA TX image

From the repository root, build the Philips-I2S TX bitstream with:

```sh
ENGR433-Solutions/Lab_10/build_tx.sh
```

The default output directory is `ENGR433-Solutions/Lab_10/build-tx/`. The
script produces `lab10_tx_top.asc`, `lab10_tx_top.bin`, and the nextpnr timing
report. The packed `.bin` can be embedded in the Pico firmware build.

The generated image uses the following contract:

- BCK: 3.072 MHz at 48 kHz, or 6.144 MHz at 96 kHz.
- WS: 48 kHz or 96 kHz, with 32-bit left and right slots.
- WS changes on the rising edge sampling the previous slot's final bit.
- Data changes on BCK falling edges and is sampled on rising edges.
- 24-bit I/Q samples occupy bits `[31:8]`; bits `[7:0]` are zero.

### Build the USB-working Pico firmware with the TX image

After building the FPGA image, embed it in the USB-working firmware:

```sh
FPGA_TX_BITSTREAM_BIN="$PWD/ENGR433-Solutions/Lab_10/build-tx/lab10_tx_top.bin" \
FPGA_DEFAULT_IMAGE=TX \
  Software/ddc_sdr_firmware_usb_working/build.sh
```

The resulting UF2 is
`Software/ddc_sdr_firmware_usb_working/build/ddc_sdr.uf2`. Flash this UF2 to
the Pico and use the firmware's stored-image or DFU workflow to load the
matching FPGA image.

The checked-in SDK build can be used without hardware:

```sh
cmake --build Software/ddc_sdr_firmware/build-current-validation -j2
```

Or configure a fresh build as described in
`Software/ddc_sdr_firmware/README.md`. The resulting firmware includes the
nonblocking AGC loop and the 10 MHz runtime SPI setting.

## Hardware acceptance

1. Load the Lab 09 FPGA bitstream and the rebuilt Pico firmware.
2. Confirm the initial PGA code is `0x0`.
3. Assert `FPGA_INT` and confirm the code advances to `0x1`, then the FPGA OTR
   latch clears through the 8-byte SPI command.
4. Repeat until `0xF`; confirm additional OTR events do not wrap the state.
5. Keep `FPGA_INT` low for at least 2 seconds and confirm one-step decay.
6. Confirm USB audio and CDC command handling continue during the decay wait.

Live RF reception is optional hardware evidence. The host AGC and protocol
regressions are the required reproducible proof when no board or antenna is
available.

## Persistent VNA prototype

The directory also contains a carrier-only VNA image. Unlike the transceiver
profiles, this image remains loaded for the complete measurement sweep:

- `vna_top.sv` generates a single DAC carrier from a shared phase accumulator;
- `vna_correlator.sv` multiplies the ADC stream by the same sine/cosine
  references and accumulates a 1024-sample complex snapshot;
- `vna_spi_slave.sv` controls frequency/acquisition and reads the snapshot;
- `vna.pcf` preserves the production SG48 pin contract; and
- `vna_top_tb.sv` verifies coherent carrier feedback and SPI readback.

Build and pack it from the Lab 10 directory:

```sh
cd ENGR433-Solutions/Lab_10
iverilog -g2012 -s vna_top_tb -o /tmp/vna_top_tb.vvp \
    vna_top.sv vna_nco.sv vna_correlator.sv vna_spi_slave.sv vna_top_tb.sv
vvp /tmp/vna_top_tb.vvp
yosys -p 'read_verilog -sv vna_top.sv vna_nco.sv vna_correlator.sv vna_spi_slave.sv; synth_ice40 -top vna_top -json vna_top.json'
nextpnr-ice40 --up5k --package sg48 --freq 30.72 --top vna_top \
    --pcf vna.pcf --json vna_top.json --asc vna_top.asc
icepack vna_top.asc vna_top.bin
```

The measured route closes at 39.56 MHz on the 30.72 MHz system clock, using
551 of 5280 logic cells and one 4 Kbit block RAM. The raw I and Q results are
signed 32-bit correlation sums; a host should divide by the window length and
form DUT/reference complex ratios for magnitude and phase.

The VNA SPI additions retain the existing 8-byte command frame:

| Command | Value | Meaning |
| ---: | ---: | --- |
| `01` | FCW | Set the carrier frequency control word. |
| `05` | bit 0 | Clear the previous result and start a 1024-sample window. |
| `06` | `0..3` | Select the following read register: I, Q, status, or FCW. |

After a read-select command, assert CS for a separate four-byte SPI read. The
FPGA shifts the selected register most-significant bit first. `FPGA_INT` stays
high when the window is complete and returns low on the next clear command.
The Pico's GPIO26 `REF` control remains an external analog-switch control; the
FPGA does not drive it. A sweep should acquire a reference window, switch the
analog path, acquire the DUT window, and compute the complex ratio without
reconfiguring the FPGA.

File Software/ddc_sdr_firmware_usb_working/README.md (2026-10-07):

# Dev-iCE DDC SDR firmware

This application is the Dev-iCE successor to the earlier Si5351a/Tayloe/
PCM1808 implementation. The FPGA replaces the Si5351a LO, Tayloe detector, and PCM1808 audio ADC path. It
receives the FPGA's I/Q stream as PCM1808-compatible I2S and exposes the same
UAC1 stereo 24-bit capture format to SDR++ or Quisk.

## Dev-iCE Pico pins

| Signal | GPIO | Direction | Notes |
| --- | ---: | --- | --- |
| FPGA SPI0 MISO | 4 | Pico input | Runtime telemetry / SPI readback |
| FPGA SPI0 CS | 5 | Pico output | Shared CS for boot CRAM and runtime SPI |
| FPGA SPI0 SCK | 6 | Pico output | 10 MHz runtime SPI clock |
| FPGA SPI0 MOSI | 7 | Pico output | Runtime command frames to FPGA |
| FPGA I2S RX_DATA | 14 | Pico input | Baseband SDR I/Q audio from FPGA (Pin 11) |
| FPGA I2S BCK | 15 | Pico input | 3.072 MHz Bit Clock from FPGA (Pin 12) |
| FPGA I2S WS | 16 | Pico input | 48 kHz Word Select / LRCLK from FPGA (Pin 9) |
| FPGA I2S TX_DATA | 13 | Pico output | Transmit audio to FPGA (Pin 10) |
| FPGA interrupt | 0 | Pico input | Active-high OTR clipping notification |
| PGA control mask | 8..11 | Pico outputs | PGA0..PGA3 digital step attenuators |
| FPGA CDONE | 21 | Pico input | HIGH when FPGA CRAM boot is complete |
| FPGA CRESET | 22 | Pico output | Active-low FPGA hardware reset |
| REF Multiplexer | 26 | Pico output | **0 = SDR RF Antenna RX**, 1 = VNA Input |
| T/R Switch | 28 | Pico output | **1 = RX Mode**, 0 = TX Mode |
| Onboard Pico LED | 25 | Pico output | Toggles on FREQ and RATE tuning activity |
| 30.720 MHz clock | FPGA pin 37 | External oscillator | Master DSP clock reference |

The FPGA is the I2S master. The firmware supports 48 kHz (and 96 kHz)
UAC1 streaming, with standard Philips I2S framing, two channels (Left = I, Right = Q),
24 valid bits, and little-endian three-byte (`S24_3LE`) USB samples.

### I2S edge contract

The FPGA changes `WS` on the BCK rising edge that samples the previous
channel's final bit. It presents the new channel's MSB on the following BCK
falling edge; the Pico PIO samples that MSB on the next BCK rising edge. This
is the standard Philips one-bit WS-to-data delay. Each slot has 32 BCK bits,
with the 24-bit sample in bits `[31:8]` and zero padding in bits `[7:0]`.

## FPGA SPI protocol

Runtime SPI uses the same CS as CRAM configuration, GPIO 5. The Pico sends
this versioned frame after configuration:

```text
D5 01 command 04 value[31:0] little-endian
```

Commands are:

| Command | Value |
| ---: | --- |
| `01` | Set center frequency; value is a 32-bit FCW |
| `02` | Set output sample rate, 48000 or 96000 |
| `03` | Reserved for status reads |
| `04` | Clear the FPGA's sticky OTR event when value bit 0 is set |

The four PGA GPIOs form a hardware control mask: `PGA0` is the least-
significant bit and `PGA3` is the most-significant bit. This is not a linear
attenuation number. The verified gain states are:

| Mask | Hardware action | Nominal gain |
| ---: | --- | ---: |
| `0x0` | All MOSFETs off; straight path | `+40 dB` |
| `0x1` | 5 dB pad engaged | `+35 dB` |
| `0x3` | 5 dB and 10 dB pads engaged | `+25 dB` |
| `0xF` | All pads engaged; both LNAs bypassed | `-15 dB` |

The automatic overload path uses only the monotonic, verified sequence
`0x0 -> 0x1 -> 0x3 -> 0xF`. It starts at `0x0`, advances after each FPGA
OTR interrupt, and remains at `0xF` after the final step. Other masks remain
available for manual calibration, but are not selected automatically until
their gain has been measured.

The FPGA latches an OTR event, holds `fpga_int` high, and keeps it high
until it receives the `DDC_FPGA_CMD_CLEAR_OTR` command.

## CDC Serial Command Reference

The USB CDC interface (`/dev/ttyACM0`) supports interactive terminals (`picocom`, `minicom`, PuTTY)
with support for both `\r` (CR) and `\n` (LF) line endings, backspace (`0x08` / `0x7F`), and Ctrl+C (`0x03`).

| Command | Response | Description |
| :--- | :--- | :--- |
| `VER` | `VER,DDC SDR 0.1` / `OK` | Reports firmware version |
| `MODE` | `MODE,DDC` / `OK` | Reports SDR architecture mode (`DDC`) |
| `XTAL` | `XTAL,30720000` / `OK` | Reports master clock frequency in Hz |
| `FPGA,STATUS` | `FPGA,RX` / `OK` | Reports currently active FPGA image (`RX`, `TX`, or `DFU`) |
| `FPGA,LOAD,RX` | `FPGA,RX` / `OK` | Reconfigures FPGA CRAM with stored RX image |
| `FPGA,LOAD,TX` | `FPGA,TX` / `OK` | Reconfigures FPGA CRAM with stored TX image |
| `FREQ,<hz>` | `<hz>` / `OK` | Sets NCO tuning frequency in Hz (calculates 32-bit FCW) |
| `RATE,<hz>` | `RATE,<hz> OK` | Sets baseband audio sample rate in Hz (e.g. 48000) |
| `REF` | `REF,<0\|1>` / `OK` | Queries front-end RF multiplexer (`0` = SDR RF RX, `1` = VNA) |
| `REF,<0\|1>` | `REF,<0\|1>` / `OK` | Sets front-end RF multiplexer (`0` = SDR RF RX, `1` = VNA) |
| `PGA` | `PGA,<code>` / `OK` | Queries current PGA digital attenuator code (`0` = max $+40\text{ dB}$ gain) |
| `PGA,<code>` | `PGA,<code>` / `OK` | Sets PGA digital attenuator code (`0..15`) |
| `DEBUG` | `DEBUG: ready=...` / `OK` | Reports real-time DMA, I2S toggle counts, and GPIO states |
| `BOOTSEL` | `REBOOTING_BOOTSEL` | Soft-reboots the RP2040 into USB BOOTSEL flash mode |
| `HELP` / `?` | Command list / `OK` | Lists all available interactive CDC commands |

## Build

The firmware CMake project requires both the Raspberry Pi Pico SDK and the
Dev-iCE SDK integration. Set `PICO_ICE_SDK_PATH` to a checkout containing
`cmake/preinit_pico_ice_sdk.cmake`; set `PICO_SDK_PATH` if the Pico SDK is not
under that Dev-iCE checkout. The checked-in `build.sh` also accepts
`FPGA_RX_BITSTREAM_BIN`, `FPGA_TX_BITSTREAM_BIN`, and `FPGA_DEFAULT_IMAGE`.

For example, to build the USB firmware with the Lab 10 TX image selected at
boot:

```sh
PICO_ICE_SDK_PATH=/path/to/pico-ice-sdk \
FPGA_TX_BITSTREAM_BIN="$PWD/ENGR433-Solutions/Lab_10/build-tx/lab10_tx_top.bin" \
FPGA_DEFAULT_IMAGE=TX \
Software/ddc_sdr_firmware_usb_working/build.sh
```

The resulting board image is `Software/ddc_sdr_firmware_usb_working/build/ddc_sdr.uf2`.

Use the checked-in Pico SDK through the SDK port. Without a bitstream, the
firmware builds as a USB/DFU development image and waits for FPGA CRAM to be
loaded:

```sh
cmake -S Software/ddc_sdr_firmware -B Software/ddc_sdr_firmware/build \
    -DPICO_BOARD=pico_dev_ice -DPICO_NO_PICOTOOL=1
cmake --build Software/ddc_sdr_firmware/build -j2
```

For a production UF2 that configures the FPGA at every Pico boot, pass the
packed `icepack` output. The legacy `FPGA_BITSTREAM_BIN` variable is treated as
the stored RX image:

```sh
cmake -S Software/ddc_sdr_firmware -B Software/ddc_sdr_firmware/build-embedded \
    -DPICO_BOARD=pico_dev_ice -DPICO_NO_PICOTOOL=1 \
    -DFPGA_BOOT_MODE=STORED \
    -DFPGA_BITSTREAM_BIN=/path/to/ddc_sdr_rx.bin
cmake --build Software/ddc_sdr_firmware/build-embedded -j2
```

To store separate RX and TX images in the Pico firmware and boot into TX by
default, use:

```sh
cmake -S Software/ddc_sdr_firmware -B Software/ddc_sdr_firmware/build-stored \
    -DPICO_BOARD=pico_dev_ice -DPICO_NO_PICOTOOL=1 \
    -DFPGA_BOOT_MODE=STORED -DFPGA_DEFAULT_IMAGE=TX \
    -DFPGA_RX_BITSTREAM_BIN=/path/to/ddc_sdr_rx.bin \
    -DFPGA_TX_BITSTREAM_BIN=/path/to/lab10_tx.bin
cmake --build Software/ddc_sdr_firmware/build-stored -j2
```

`FPGA_BOOT_MODE=DFU` builds the development behavior: the Pico does not load
an image at reset and waits for `dfu-util`. `FPGA_BOOT_MODE=STORED` loads the
selected embedded image at every reset. `FPGA_DEFAULT_IMAGE` chooses RX or TX
when both images are present. The stored images are generated as separate C
arrays, so the same firmware can switch between them without reflashing the
Pico.

The `.uf2` flashes the RP2040. Dev-iCE has no FPGA configuration flash, so
FPGA CRAM is volatile and must be loaded again after reset or power loss.

While the firmware is running, the CDC control port accepts:

```text
FPGA,STATUS
FPGA,LOAD,RX
FPGA,LOAD,TX
```

`FPGA,LOAD,RX` and `FPGA,LOAD,TX` stop audio DMA, force GPIO28 high for
receive, release runtime SPI, reload the selected stored CRAM image, restore
the sample-rate and audio streams, and then allow the normal TX start path to
assert GPIO28 low. A missing image returns an error. `FPGA,STATUS` reports the
active image or `DFU`. The existing `DFU,PREPARE` and `dfu-util` workflow is
unchanged and remains useful for development images that are not embedded.

These are deployment and transceiver-profile choices. Use DFU while developing
or testing a new image, and use STORED when the Pico should boot a known image
from its own flash. If both stored images are embedded, RX and TX can be
selected at boot or between transceiver sessions with the `FPGA_DEFAULT_IMAGE`
setting and the `FPGA,LOAD,*` commands.

Do not use RX/TX CRAM switching as the ordinary VNA mode switch. A VNA sweep
needs its stimulus, reference, receive channel, and measurement processing to
remain clock-coherent for the entire sweep. VNA support therefore needs one
persistent VNA-capable FPGA design, either as its own stored image selected
before the measurement or as part of an integrated design; reconfiguration is
only a between-session operation.

## Development bitstream update

Stop or close the SDR++/Quisk audio stream before updating. Then run:

```sh
python3 Software/ddc_sdr_firmware/tools/dfu_fpga.py /path/to/ddc_sdr.bin
```

The helper sends `DFU,PREPARE`, which stops I2S/DMA and releases runtime SPI,
then invokes:

```sh
dfu-util -d 1209:b1c0 -a 0 -D /path/to/ddc_sdr.bin
```

The SDK's DFU callback streams the raw packed bitstream into FPGA CRAM and
checks CDONE. The Pico remains running; after a successful transfer it
reinitializes runtime SPI, restores the selected rate, and restarts I2S. The
helper deliberately does not pass `-R`, because a reset would clear volatile
CRAM and would also discard a bitstream that was only loaded through DFU.

The SDK also prepares automatically when the first DFU block arrives, so
`--skip-prepare` is available for manual testing:

```sh
python3 Software/ddc_sdr_firmware/tools/dfu_fpga.py --skip-prepare /path/to/ddc_sdr.bin
```

## Current gateware dependency

This directory defines the Pico-side contract but does not invent the DDC HDL
or its `.pcf`. Add the FPGA top level and Dev-iCE constraints separately, then
synthesize with `yosys`, place and route with `nextpnr-ice40`, pack with
`icepack`, and pass the resulting `.bin` to the build or DFU helper.

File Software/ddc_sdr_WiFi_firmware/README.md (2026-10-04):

# Dev-iCE DDC SDR Wi-Fi Firmware (OpenHPSDR Protocol 1)

This application runs on the **Raspberry Pi Pico W** on the Dev-iCE board. It interfaces with the iCE40 FPGA digital down-converter (DDC), receives 24-bit stereo I/Q samples over I2S via PIO, and streams them wirelessly over Wi-Fi using the standard **OpenHPSDR Protocol 1 (UDP port 1024)**.

All radio tuning, sample rate switching, and step-attenuator gain control are handled natively via OpenHPSDR Protocol 1 Command & Control (C&C) packets. All USB protocols (CDC and UAC1) have been removed, eliminating resource contention and timing conflicts.

## Compatible SDR Software

The firmware identifies as an **OpenHPSDR Hermes** device and works seamlessly with:
- **SDR++** (Select source: *Hermes*)
- **Quisk** (OpenHPSDR / Hermes hardware driver)
- **PowerSDR / Thetis**
- **SparkSDR**
- **linHPSDR**

## Dev-iCE Pico W Hardware Pinout

| Signal | GPIO | Direction | Notes |
| --- | ---: | --- | --- |
| FPGA SPI0 MISO | 4 | Pico input | Runtime SPI readback |
| FPGA SPI0 CS | 5 | Pico output | Shared CS for boot CRAM and runtime SPI |
| FPGA SPI0 SCK | 6 | Pico output | 10 MHz runtime SPI clock |
| FPGA SPI0 MOSI | 7 | Pico output | Runtime command frames to FPGA |
| FPGA I2S RX_DATA | 14 | Pico input | Baseband SDR I/Q audio from FPGA (Pin 11) |
| FPGA I2S BCK | 15 | Pico input | 3.072 MHz Bit Clock from FPGA (Pin 12) |
| FPGA I2S WS | 16 | Pico input | 48 kHz / 96 kHz Word Select from FPGA (Pin 9) |
| FPGA interrupt | 0 | Pico input | Active-high OTR clipping notification |
| PGA control mask | 8..11 | Pico outputs | PGA0..PGA3 digital step attenuators |
| FPGA CDONE | 21 | Pico input | HIGH when FPGA CRAM boot is complete |
| FPGA CRESET | 22 | Pico output | Active-low FPGA hardware reset |
| REF Multiplexer | 26 | Pico output | **0 = SDR RF Antenna RX**, 1 = VNA Input |
| T/R Switch | 28 | Pico output | **1 = RX Mode**, 0 = TX Mode |
| 30.720 MHz clock | FPGA pin 37 | External oscillator | Master DSP clock reference |

The FPGA is the I2S master. The firmware supports **48 kHz** and **96 kHz** sample rates, with Philips I2S framing, two channels (Left = I, Right = Q), 24 valid bits, and packages them into standard 1032-byte OpenHPSDR Protocol 1 EP6 packets (126 stereo samples / 252 words per packet).

## Automatic Gain Control (AGC) & Step Attenuators

The four PGA GPIOs (8..11) control the RF front-end step attenuators:
- `0x0`: Straight path, max gain (+40 dB)
- `0x1`: 5 dB pad engaged (+35 dB)
- `0x3`: 5 dB and 10 dB pads engaged (+25 dB)
- `0xF`: All pads engaged (-15 dB)

When an ADC overload occurs, the FPGA triggers an interrupt on GPIO 0. The firmware steps down the gain and clears the OTR condition. If the signal remains below threshold, the AGC decays back towards max sensitivity.

## Building for Pico W

Run the build script:

```bash
cd Software/ddc_sdr_WiFi_firmware
bash build_picow.sh
```

This compiles the firmware and embeds the DDC FPGA bitstream (`bitstreams/ddc_sdr_rx.bin`). The resulting binary is generated at:
```text
Software/ddc_sdr_WiFi_firmware/build-picow/ddc_sdr.uf2
```

## Flashing the Pico W

1. Put the Raspberry Pi Pico W in BOOTSEL mode: hold the BOOTSEL button while plugging the USB cable into your computer.
2. The `RPI-RP2` mass storage drive will appear.
3. Copy the firmware UF2:
   ```bash
   cp build-picow/ddc_sdr.uf2 /media/$USER/RPI-RP2/
   ```
4. The Pico W will reboot automatically, program the FPGA CRAM from flash, and connect to Wi-Fi.

## Wi-Fi Configuration

Settings are configured in [`wifi_config.h`](wifi_config.h):
- Primary SSID: `Frohne-Shop-2.4GHz`
- Secondary SSID: `Frohne-2.4GHz`
- Fallback Static IP: `192.168.1.191` (used if DHCP lease times out)
- Subnet Gateway: `192.168.1.1` | Netmask: `255.255.255.0`

## Pico W Status LED

The onboard Wi-Fi LED indicates connection and streaming state:

| Blink Pattern | Rate | Meaning |
| :--- | :--- | :--- |
| **Solid ON** | Constant | **Active SDR Streaming**: SDR client is actively receiving I/Q data. |
| **Steady Heartbeat** | 1 Hz | **Wi-Fi Connected (`CYW43_LINK_UP`)**: Listening for OpenHPSDR discovery. |
| **Medium Blink** | 2 Hz | **Associating / Acquiring IP** (`CYW43_LINK_JOIN` / `NO_IP`). |
| **Slow Blink** | 0.5 Hz | **Scanning / Reconnecting** (`CYW43_LINK_DOWN`). |

## Diagnostic & Verification Tools

### 1. Unified OpenHPSDR Test Suite
To verify network discovery, frequency tuning, streaming continuity, packet arrival delta, and I/Q balance:
```bash
python3 test_openhpsdr.py
```

### 2. Stream & FFT Spectrum Verification
To capture live packets and analyze the RF spectrum:
```bash
python3 test_openhpsdr_stream.py 192.168.1.191
```

### 3. Comprehensive Protocol 1 Compliance Test
```bash
python3 test_pico_w_openhpsdr.py --ip 192.168.1.191 --seconds 5.0
```

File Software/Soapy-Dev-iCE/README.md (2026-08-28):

# SoapySDR Driver for Pico-Dev-iCE DDC SDR & WWU 2026 SDR

A native [SoapySDR](https://github.com/pothosware/SoapySDR) module and hardware driver for the **Pico-Dev-iCE DDC SDR** (RP2040 + iCE40UP5K FPGA Software Defined Radio board) and the **WWU 2026 SDR** board.

This driver exposes the board as a standard SoapySDR receiver device, making it compatible with SDR software such as **SDR++**, **GQRX**, **GNU Radio**, and **CubicSDR**.

---

## Hardware Architecture & How It Works

```
                       ┌────────────────────────────────────────┐
                       │          Pico-Dev-iCE Board            │
                       │                                        │
[ Antenna ] ──> [ Front End / PGA ] <── [ MS9280 High-Speed ADC ]
                        │                         │             │
                    RF Signal                     │ 30.72 MSPS  │
                        ▼                         ▼             │
                [ iCE40UP5K FPGA ] ── NCO / Mixer / CIC DDC     │
                        │                                       │
                     I2S I/Q (24-bit stereo)                    │
                        ▼                                       │
                 [ RP2040 MCU ]                                 │
                        │                                       │
                        └────────────┬────────────┘             │
                                     │ USB                      │
                       ┌─────────────┴────────────┐             │
                       │  USB Audio   │  USB CDC  │             │
                       └──────┬───────┴─────┬─────┘             │
                              │             │                   │
══════════════════════════════╪═════════════╪═══════════════════╪══════════════════
 HOST COMPUTER                │             │
                              ▼             ▼
                       [ miniaudio ]   [ SerialPort ]
                        (Direct ALSA)   (115200 baud)
                              │             │
                              └──────┬──────┘
                                     ▼
                              [ Soapy2026SDR ]
                                     │
                                     ▼
                              [ SDR++ / GQRX ]
```

### 1. Control Protocol (USB CDC Serial)
* **Discovery:** Scans available serial ports for USB Vendor/Product IDs `0x1209:0xB1C0` (Pico-Dev-iCE DDC SDR) as well as `0xCAFE:0x4011` / `0xCAFE:0x4010` (WWU 2026 SDR).
* **Direct NCO Frequency Tuning (DDC):** When tuning frequency, the driver sends `FREQ,<hz>\r\n`. The RP2040 firmware computes the 32-bit frequency tuning word (FCW) and programs the FPGA NCO over SPI.
* **Dual Sample Rate (48 kHz / 96 kHz):** Supports dynamic switching between 48,000 Hz and 96,000 Hz via `RATE,<hz>\r\n`.
* **PGA Gain Control:** Digital step attenuator codes (0x0 = +40 dB, 0x1 = +35 dB, 0x3 = +25 dB, 0xF = -15 dB) via `PGA,<code>\r\n`.
* **Antenna Switching:** Front-end RF switch via `REF,<0|1>\r\n` (0 = Antenna RX, 1 = VNA Input).

### 2. Audio & I/Q Baseband Capture (USB Audio)
* **ADC / DDC:** The FPGA streams I2S baseband samples (Left = I, Right = Q) at 24-bit resolution (`S24_3LE`) into the RP2040 at 48 kHz or 96 kHz.
* **ALSA Direct Bypass:** Binds directly to the ALSA hardware device `hw:CARD=D2026,DEV=0` (or `hw:CARD=SDR,DEV=0`) using `miniaudio` with `noAutoResample = true` to prevent any OS audio resampling.
* **Buffering & Format Conversion:** Converts 24-bit PCM samples to normalized float32 complex samples (`CF32` or `CS16`) in an internal lock-protected ring buffer.

---

## Dependencies & Prerequisites

### Linux (Ubuntu / Debian / Raspberry Pi OS)
```bash
sudo apt update
sudo apt install -y \
    build-essential \
    cmake \
    git \
    libsoapysdr-dev \
    soapysdr-tools \
    libasound2-dev \
    libudev-dev \
    python3-soapysdr \
    python3-numpy
```

### Serial Port Permissions
Make sure your user has permissions to access USB serial ports (`/dev/ttyACM*`):
```bash
sudo usermod -a -G dialout $USER
```
*(Log out and back in if this was just added).*

---

## Building and Installing

1. **Build and install using the build script:**
   ```bash
   cd Software/Soapy-Dev-iCE
   bash build.sh
   ```

2. **Or build manually with CMake:**
   ```bash
   cd Software/Soapy-Dev-iCE
   mkdir -p build && cd build
   cmake .. -DCMAKE_BUILD_TYPE=Release -DCMAKE_INSTALL_PREFIX=/usr/local
   make -j$(nproc)
   sudo make install
   sudo ldconfig
   ```

3. **Verify the installation:**
   Ensure the board is plugged into USB, then run:
   ```bash
   SoapySDRUtil --find="driver=2026sdr"
   ```
   Or probe full details:
   ```bash
   SoapySDRUtil --probe="driver=2026sdr"
   ```

4. **Run the functional test (optional):**
   ```bash
   python3 test_driver.py --freq 7100000 --rate 48000
   ```

---

## Using with SDR++

1. **Launch SDR++:**
   ```bash
   sdrpp
   ```
2. **Select Source:**
   * In the top-left **Source** panel, select **SoapySDR**.
3. **Select Device:**
   * In the device drop-down, select **WWU Dev-iCE DDC SDR** (or **DDC SDR 2026**).
   * If it doesn't appear, click the **Refresh** button next to the device list.
4. **Configure Parameters:**
   * **Sample Rate:** Select `48000` (48 kHz) or `96000` (96 kHz).
   * **Antenna:** Select `RX` (for HF Antenna input) or `VNA` (for VNA input).
   * **Gain:** Adjust between `-15 dB` and `+40 dB` (maps to FPGA PGA attenuation states).
5. **Start Receiving:**
   * Click the **Play (▶)** button in the top-left.
   * Tune to your desired HF frequency (e.g. `7.100 MHz` for 40m amateur band, `14.200 MHz` for 20m amateur band).
   * Choose demodulation (AM, LSB, USB, CW, etc.) in the Radio panel.

---

## Troubleshooting

* **Device not detected by `SoapySDRUtil --find`:**
  * Check USB connection: `lsusb` should show `1209:b1c0` (or `cafe:4011`/`cafe:4010`).
  * Check serial port exists: `ls -la /dev/ttyACM*`.
  * Ensure the module was installed to the SoapySDR search path (inspect paths with `SoapySDRUtil --info`).
* **Permission denied on `/dev/ttyACM*`:**
  * Run `sudo usermod -a -G dialout $USER` and log back in.
* **Audio device not found / no sound in SDR++:**
  * Check `cat /proc/asound/cards` to verify the USB audio device is enumerated.

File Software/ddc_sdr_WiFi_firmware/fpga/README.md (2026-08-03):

# DDC FPGA handoff

The [`ddc_sdr.pcf`](ddc_sdr.pcf) file is the Dev-iCE SG48 package map for the
DDC top level. It intentionally contains signal names rather than a generated
bitstream; the HDL team can choose the internal module structure while keeping
the board contract stable.

The minimum first-pass top level must:

- sample `adc_data[7:0]` with `adc_clk` from the 30.720 MHz `clk` domain;
- provide the runtime SPI slave on `spi_*` while `spi_cs` is asserted;
- emit standard I2S on `i2s_rx_data`, `i2s_bck`, and `i2s_ws` to Pico GPIOs
  14, 15, and 16;
- accept the versioned `D5 01 command 04 value` frames described by the
  parent README;
- expose a deterministic 48 kHz path first, then a tested 96 kHz path.

The 96 kHz path needs explicit clocking design. A 30.720 MHz source provides
320 master-clock cycles per 96 kHz frame, but a 64fs I2S bit clock would be
6.144 MHz. Do not implement that mode using an integer divide of the raw
30.720 MHz clock; use a suitable PLL/derived clock or a formally verified
fractional edge scheduler and validate BCK/WS on hardware.

Example build flow:

```sh
yosys -p 'synth_ice40 -top ddc_sdr -json ddc_sdr.json' *.v
nextpnr-ice40 --up5k --package sg48 --freq 30.72 \
    --top ddc_sdr --pcf fpga/ddc_sdr.pcf \
    --json ddc_sdr.json --asc ddc_sdr.asc
icepack ddc_sdr.asc ddc_sdr.bin
```

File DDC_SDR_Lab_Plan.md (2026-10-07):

# DDC SDR HDL Lab Plan

This is a ten-week, hands-on introduction to FPGA design using the Pico
Dev-iCE DDC receiver. Students already know the QSD SDR signal path and some
DSP math. The new material is HDL: clocks, registers, serial protocols,
simulation, and how to test code generated with AI.

The sequence is deliberately gentle. Students see a real board in Week 1,
learn to test simple logic in Week 2, learn two useful protocols, and only then
take on the NCO, mixer, and CIC filter.

## Course Shape

- Students work in pairs. Each pair owns an independent implementation of the
  common baseline.
- Every week has four parts: a short explanation, a small lab, a testbench, and
   a hardware demonstration when the board supports it.
- The common project is a 48 kHz, receive-only DDC path that is simulated,
   self-checking, and synthesizable for the Dev-iCE iCE40UP5K.
- Boards should be in students' hands from Week 1. Hardware demonstrations
   motivate the work, but a passing result never depends on a particular RF
   signal, antenna, or board revision.
- Students may use AI for RTL, testbench scaffolding, scripts, and debugging,
  but the pair is responsible for the specification, expected results, test
  intent, and explanation of every submitted line.

The board and software contracts are documented in the root
[`README.md`](README.md), the FPGA handoff
[`Software/ddc_sdr_firmware/fpga/README.md`](Software/ddc_sdr_firmware/fpga/README.md),
and the checked-in constraints
[`ddc_sdr.pcf`](Software/ddc_sdr_firmware/fpga/ddc_sdr.pcf). Resolve conflicts
between those documents, the schematic, and the netlist in Week 1 before
writing datapath RTL.

## How Students Work

For every lab, students answer these questions before asking AI for RTL:

1. What should the circuit do on each clock edge?
2. What should happen during reset and for bad input?
3. What simple example proves that it works?
4. What believable bug should the testbench catch?

The weekly submission then contains:

1. A short specification, including widths, signedness, timing, and reset.
2. A self-checking SystemVerilog testbench with useful failure messages.
3. An independent reference calculation or golden vector when numbers are
   involved.
4. RTL, the command used to run it, and the test result.
5. One intentionally broken version that the testbench catches.
6. A short AI-use note naming one generated mistake the students corrected.

A waveform screenshot can explain a failure, but it is not evidence by itself.
A test passes only when the checker would fail for a plausible implementation
error. For DSP numbers, students should use a Python calculation or
hand-derived vectors rather than copying the RTL algorithm into the checker.

## Weeks 1-2: Start Here

### Week 1: Board, Schematic, and Clock Budget

**Goal:** understand the physical board and make the toolchain work.

Students install the OSS CAD Suite, inspect the KiCad schematic, identify the
SPI, I2S, ADC, DAC, interrupt, and PGA pins, and trace one sample through the
planned signal path. They calculate:

- 30.720 MHz / 640 = 48 kHz;
- 48 kHz * 64 = 3.072 MHz I2S bit clock;
- two 32-bit I2S slots with 24 valid bits each.

**Hardware payoff:** connect the board, verify that the Pico boots, identify
the FPGA status LED, and run the smallest known-good FPGA bitstream. This is a
power and bring-up check, not an RF experiment.

**Evidence:** a one-page annotated block diagram, pin table, clock budget,
and a successful toolchain/board bring-up log.

### Week 2: Traffic Light and AI Verification

**Goal:** learn the edit-simulate-explain loop with very small HDL.

AI writes a traffic-light state machine for the RGB LEDs. Students write the
testbench first, then ask AI for the RTL. The testbench must catch an incorrect
reset state and an off-by-one timer.

The timer must be parameterized. The testbench uses a tiny divider so it runs
quickly; the hardware build uses a divider that gives an approximately
one-second interval. This teaches students not to simulate a full second for
every test.

**Hardware payoff:** flash the FPGA and watch the physical LEDs change.

**Evidence:** a specification, self-checking testbench, waveform showing the
state transitions, a caught broken version, and an AI-use note.

## Weeks 3-10: DDC Project

### Week 3: I2S Audio Transmitter

**Goal:** learn clock division, shift registers, and serial timing.

AI generates a simple FPGA-master I2S transmitter. Start with two fixed sample
values, then try a repeating sawtooth sequence. The testbench checks the exact
relationship between BCK, WS, and data: 48 kHz WS, 3.072 MHz BCK, two 32-bit
slots, 24 valid MSB-first bits, and the standard one-bit I2S data delay.

The checked-in implementation uses the Philips edge contract consistently:
`WS` changes on the BCK rising edge that samples the previous slot's final
bit; the new channel MSB is driven on the following BCK falling edge and
sampled on the next rising edge. `WS=0` is left/I and `WS=1` is right/Q.
The 24-bit sample occupies bits `[31:8]` of each 32-bit slot and bits `[7:0]`
are zero. This edge relationship must be checked in waveforms, not inferred
only from reconstructed sample words.

Do not begin by trying to make the sound impressive. First prove that a logic
analyzer or testbench can reconstruct the two known samples from the bitstream.

**Hardware payoff:** connect the FPGA I2S output to the existing Pico firmware
and observe captured samples on the host. Hearing a repeating test pattern is a
good bonus, but a logic-analyzer capture is the required hardware evidence.

**Evidence:** a timing diagram, self-checking serializer testbench, and a
captured or simulated reconstruction of both channels.

### Week 4: SPI Command Parser

**Goal:** receive serial commands and update a register safely.

AI generates an SPI slave and command parser for the versioned frame documented
in [`ddc_protocol.h`](Software/ddc_sdr_firmware/ddc_protocol.h):
`D5 01 command 04 value[31:0]` in little-endian order. Begin with one harmless
test register. Then add frequency, sample-rate, and OTR-clear commands.

The first version works in one clock domain. Only after that test passes should
students add the CDC mailbox or handshake that transfers a complete command to
the 30.720 MHz domain. Tests cover bad sync/version/length fields, aborted chip
select, back-to-back frames, and randomized clock phase.

**Hardware payoff:** send commands from the Pico and observe a test register,
LED, or logic-analyzer output change. The current public protocol does not
directly command the PGA pins; those pins are controlled by the Pico's OTR/AGC
path. Do not promise a PGA toggle for an SPI-parser lab until that command is
explicitly added to the protocol.

**Evidence:** parser tests that reject malformed frames, commit valid frames
exactly once, and never expose a half-updated multi-bit value.

### Week 5: ADC Capture and OTR Latch

**Goal:** capture the fast ADC bus and make clipping visible to the Pico.

Students capture `adc_data[7:0]` in the 30.720 MHz domain and implement the OTR
event contract. The testbench uses OTR pulses aligned to the ADC clock, then
checks that the FPGA interrupt remains high until a valid clear command. It
covers zero, full-scale, alternating, ramp, and PRBS ADC values; reset during
an event; repeated events; and clear/retrigger behavior.

The OTR input is described as a roughly 32 ns event because it is one sample
clock period. A synchronous design cannot guarantee to see an arbitrary pulse
that occurs entirely between clock edges. If the real signal is asynchronous,
students must state and test an asynchronous capture strategy instead.

The interrupt is deliberately sticky rather than a fixed one-millisecond
pulse. This gives the Pico time to respond and matches the existing firmware
contract: `fpga_int` stays high until `DDC_FPGA_CMD_CLEAR_OTR` is accepted.

**Hardware payoff:** use a safe, current-limited signal source or an instructor
test fixture to exercise the OTR path. Never touch the ADC input to create
static; that can damage the analog front end. The Pico should report the
interrupt and step through the verified PGA masks `0x0 -> 0x1 -> 0x3 -> 0xf`.

**Evidence:** ADC capture tests, OTR timing evidence, and a hardware interrupt
log. A complete level-regulating AGC is an extension.

### Week 6: NCO

**Goal:** introduce DSP inside a familiar clocked module.

AI generates a 32-bit phase accumulator and a sine/cosine lookup or equivalent
approximation. Students choose a tuning word, predict the frequency, save the
simulated output, and plot it in Python or another approved tool. The testbench
checks phase wraparound, zero and positive/negative frequencies, lookup-table
quantization, and signed extremes.

**Hardware payoff:** after the digital simulation passes, route the NCO to the
FPGA DAC interface and observe a safe test signal at `AWG_OUT` with an
oscilloscope. Begin with a low-risk configuration and verify the DAC clock,
data coding, termination, and analog output path before interpreting the
waveform.

**Evidence:** independent frequency calculation, plot, simulation test, and
optional oscilloscope capture.

### Week 7: Digital Mixer

**Goal:** learn signed fixed-point multiplication and complex mixing.

Students mix a known ADC tone with the NCO output. Use a frequency choice that
is easy to predict, such as a 7 MHz input and a 7 MHz NCO, and verify that the
desired product produces a DC or near-DC baseband component. Also test a
nonzero difference frequency and the unwanted sum component.

The reference must define signed widths, multiplication width, truncation or
rounding, and I/Q sign convention. Tests must include positive and negative
values, zero, maximum positive, and maximum negative values.

**Hardware payoff:** a plotted simulation result is the main demonstration.
Students should be able to point to the DC result and explain why it appears;
an RF hardware demonstration is optional.

**Evidence:** signed-arithmetic reference calculations, mixer testbench, and
plots showing the expected difference and sum frequencies.

### Week 8: CIC Decimator

**Goal:** handle multirate DSP, bit growth, and output-valid timing.

Students design a three-stage CIC decimator with `R=640`. Before writing RTL,
they calculate the maximum gain, register growth, scaling, latency, and
decimation phase. For a three-stage filter, the gain is $R^3=640^3$ and the
decimation gain requires about 28 additional bits because
$\lceil\log_2(640^3)\rceil=28$; the final width also depends on the input and
mixer widths. The testbench, not an AI guess, decides whether the chosen width
is sufficient.

Tests cover impulse, step, constant input, tones inside and outside the
passband, reset, signed extremes, wraparound behavior, and output-valid
alignment. Students may use a deliberately broken width calculation to learn
from the failure, but they should not rely on uncontrolled overflow as the
lesson.

**Hardware payoff:** none is required. This is the difficult verification week
and should remain focused.

**Evidence:** bit-growth calculation, independent model, self-checking tests,
and a written explanation of the chosen arithmetic behavior.

### Week 9: System Integration

**Goal:** connect blocks that have already been tested separately.

Students integrate ADC capture, NCO, mixer, CIC, I2S, SPI control, reset, and
OTR notification. The top-level testbench drives deterministic ADC tones and
impulses, changes frequency through the SPI model, and checks the resulting
I/Q audio samples and I2S framing.

The integration test must include at least one negative test for each control
boundary: invalid command, reset during traffic, OTR during a sample transfer,
and a frequency update near a decimator output.

**Hardware payoff:** load the complete bitstream and verify clocks, I2S, and
status signals. Use a signal generator or a known test fixture before trying an
antenna. The board is alive when the interface evidence is good; an unknown RF
environment is not a valid test failure.

**Evidence:** top-level regression, packed bitstream, and a short block-by-block
debugging record for any integration failure.

### Week 10: AGC and Radio Demonstration

**Goal:** finish the hardware/software handshake and demonstrate the receiver.

The required part is a controlled OTR/AGC demonstration using the existing Pico
firmware: the Pico receives the FPGA interrupt, advances through the verified
PGA masks, sends the OTR-clear command, and keeps the audio path running. The
current implementation is C firmware; a MicroPython AGC loop can be an
extension after the C path is understood and tested.

**Hardware payoff:** with a safe signal source, students observe the gain
state changes and clipping recovery. If the analog chain, antenna, and local
conditions are ready, they may try SDR++ or a shortwave broadcast. Live radio
reception is a celebration and extension, not the passing criterion.

**Evidence:** AGC state trace, OTR-clear transaction, final regression, and a
short hardware demonstration or simulation substitute.

The 96 kHz mode, transmit path, and other clocking extensions remain optional.
The handoff notes that 30.720 MHz does not directly provide an integer-divided
6.144 MHz I2S bit clock, so 96 kHz requires its own explicit clocking design.

## Weekly Teach-Back

Each pair has a short weekly discussion with the instructor. Both students
must participate. Each student answers:

- a signal-tracing question: what happens on a named edge or transaction;
- a prediction question: what will the next output be and why;
- a verification question: which test would catch a plausible bug;
- a reflection question: what did the AI get wrong or leave unjustified?

The pair brings its specification, evidence, one failure analysis, and current
risk list. A failed checkpoint can be redone once. The original failure and
the diagnosis remain part of the record.

## Assessment

- 20% weekly artifacts, progress, teach-backs, and quality of any redo.
- 30% verification quality: independence of the model, edge cases, assertions,
  failure messages, and regression discipline.
- 40% individual understanding and oral defense.
- 10% engineering process: version control, documentation, reproducibility,
  and honest AI-use log.

A passing project requires a working simulated 48 kHz baseline, self-checking
verification, and successful synthesis. Hardware evidence increases
confidence but does not replace simulation or penalize students while boards
are unavailable.

## Extensions

Extensions should be proposed with a written specification and a verification
plan before implementation. Suitable topics include:

- validated 96 kHz output;
- a measured level-regulating AGC loop;
- transmit DUC and DAC/I2S input;
- VNA or AWG support;
- stronger status reporting and counters;
- formal properties for the SPI parser, CDC handshake, or I2S serializer;
- real-radio or filter-sandbox hardware experiments.

TX, VNA, AWG, full AGC, and real RF reception are intentionally extensions:
they are valuable demonstrations but depend more heavily on analog hardware,
clocking, and board availability than the common HDL learning objectives.
DFU and stored FPGA images are interchangeable deployment choices for
development and transceiver profiles, but a VNA proposal must keep one
coherent FPGA design loaded for the whole sweep rather than switching RX/TX
CRAM images between points.

## Implementation Order for This Repository

The next practical build-out should follow the weekly sequence:

1. Add a traffic-light starter design, broken variant, and self-checking
   SystemVerilog testbench.
2. Add a small simulator command or Makefile target that students can run
   from the repository root.
3. Add one lab directory at a time under
   `Software/ddc_sdr_firmware/fpga/labs/`, keeping each lab's specification,
   RTL, testbench, and reference data together.
4. Keep the top-level names in `ddc_sdr.pcf` and the SPI frames in
   `ddc_protocol.h` stable while the internal RTL evolves.
5. Add hardware smoke tests alongside the simulation regression, and never use
   an unexplained hardware failure as a substitute for a missing testbench.

This order gives the class a usable verification exercise immediately and
keeps unfinished student HDL out of the production firmware build.

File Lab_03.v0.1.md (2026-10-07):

# Lab 3: The I2S Audio Transmitter

**Objective:** This week, you will bridge the FPGA to the Raspberry Pi Pico. You will learn clock division, shift registers, and the serial timing used by the board's I2S receiver. You will use provided golden vectors, use chat AI to generate bounded SystemVerilog and a self-checking testbench, and prove the bit alignment in simulation and on the hardware.

**Schedule:** Lab 3 is assigned Wednesday, October 7. The solution is discussed in lecture Friday, October 9. On Wednesday, October 14, you must be ready to continue Lab 3 and explain your progress after the October 12-13 Senior Trip. Lab 3 must be complete, tested, and ready for teaching and hardware validation at the Lab 4 meeting on Tuesday, October 20.

## AI Use Policy
Chat-based AI is permitted for this lab. You may ask a chat AI for explanations, design suggestions, or code generated from your written blueprint. Agentic AI is not permitted: do not use coding agents, autonomous IDE modes, workspace agents, or tools that inspect or modify your files, run commands, or execute tests on your behalf. You must make the edits, run the simulations, generate the golden vectors, and verify the results yourself, and you must be able to explain all submitted work.

## Part 1: The I2S Hardware Contract
The Pico is expecting to receive audio from the FPGA. The FPGA is the **I2S Master**, meaning it generates the clocks. The Pico's PIO state machine (which you used with the PCM1808 last spring quarter) is the **I2S Slave**, meaning it listens.

For this lab, use the following Dev-iCE contract. The signal names match
`Software/ddc_sdr_firmware/fpga/ddc_sdr.pcf` and the receiver in
`Software/ddc_sdr_firmware/i2s_rx.pio`:
1.  **Bit Clock (`BCK`):** Runs at exactly **3.072 MHz**.
2.  **Word Select (`WS`):** Its complete low-to-high-to-low cycle runs at exactly **48 kHz**. It changes level every 32 BCK periods.
    *   `WS = 0` indicates the **Left Channel**.
    *   `WS = 1` indicates the **Right Channel**.
3.  **Frame Size:** 64 bits total per `WS` cycle (32 bits per channel). 
4.  **Data Alignment:** We transmit a 24-bit sample in the most-significant 24 bit times of a 32-bit slot. The final 8 bit times are zero, so the slot word is `{sample[23:0], 8'b0}`. Data is MSB-first.
5.  **Philips alignment rule:** WS changes on the channel-boundary BCK rising edge, which completes the previous slot. The FPGA presents the new slot's MSB on the following BCK falling edge, and the Pico's PIO samples it on the next BCK rising edge. Each slot therefore has 32 sampled bits, with the WS transition occurring one BCK period before the new slot's MSB.
6.  **Verification requirement:** Do not infer the protocol from reconstructed words alone. Prove in the waveform that WS changes first, data changes on a falling BCK edge, and the new MSB is sampled on the following rising edge.

### The Clock Budget
Your master clock is **30.720 MHz**.
*   `BCK` has a full period of 10 master-clock cycles, so its output toggles every 5 master-clock cycles: `30.720 MHz / 10 = 3.072 MHz`.
*   A complete I2S frame is 64 BCK periods, so `3.072 MHz / 64 = 48 kHz`.
*   `WS` changes level after 32 BCK periods, because each channel occupies one 32-bit slot.

*The Sawtooth Generator:* To test this, you don't need real radio data yet. Create a 24-bit counter that increments by a small fixed amount every 48 kHz cycle. This will generate a mathematically perfect digital sawtooth wave.

---

## Part 2: Golden Vectors (The Verification)
Before you ask AI to write the SystemVerilog, you must know exactly what the output is supposed to look like. Python programming is not the goal of this lab, so the reference generator and its output are provided in `ENGR433-Solutions/Lab_03` and in the October 9 lecture notebook.

**Your Task:** Use the provided `generate_golden_vectors.py`, `expected_i2s.txt`, and `expected_words.mem` as the reference for your design. You must be able to explain how the vectors were generated and use them in your self-checking testbench. You may modify the sawtooth start value or step, but if you do, regenerate the expected files and explain the change.

---

## Part 3: The AI Prompt (The Blueprint)
Now that you know the math, use this template to prompt your AI (Claude, Gemini, or Windsurf). Fill in the brackets with your specific architectural decisions.

> **SystemVerilog I2S Transmitter Request**
> Act as a Senior ASIC Designer. Write a SystemVerilog module that acts as an I2S Audio Master and generates a Sawtooth test wave. 
> 
> **Inputs:** `clk_30m` (30.72 MHz), `reset_n`
> **Outputs:** `i2s_bck`, `i2s_ws`, `i2s_rx_data`
> 
> **Clock Generation:**
> * Use a clock-enable counter in the `clk_30m` domain. Toggle `i2s_bck` every 5 master-clock cycles to produce 3.072 MHz. Do not create a second procedural clock domain just for this exercise.
> * Change `i2s_ws` after every 32 BCK periods. Its complete cycle is 48 kHz.
> 
> **Data Generation:**
> * Create a 24-bit register `sawtooth_val` that increments by [X] every time `i2s_ws` completes a full cycle. 
> 
> **I2S Shift Register:**
> * Change `i2s_ws` on the channel-boundary rising edge. Present the new slot's first data bit on the following BCK falling edge so it is valid for the next BCK rising-edge sample, matching standard Philips I2S.
> * `i2s_ws` = 0 is Left and `i2s_ws` = 1 is Right. Send `{sawtooth_val, 8'b0}` MSB-first. Send the same sample in both slots and increment it once per complete 64-bit frame.

---

## Part 4: The Self-Checking Testbench
Do not trust the AI's shift register logic. "Off-by-one" bit shifts are the most common AI hallucination in serial protocols.

Use the provided `i2s_tb.sv` as a starting point, and use chat AI to help generate or explain the checks. You must understand and be able to defend every check. Your testbench must:
1. Instantiates your module and drives the 30.72 MHz clock.
2. Uses an `always @(posedge i2s_bck)` block to act exactly like the Pico's PIO state machine.
3. It must observe each BCK rising edge, verify the WS level, collect the next 32 sampled bits into a shift register, and compare that word against the values in the file generated by Python.
4. **Inject a Bug:** Purposely shift the first bit of one slot or change the WS boundary by one BCK edge. Prove that your testbench throws a `$display("FAIL")` error.

The provided solution checks six channel slots in simulation: three left slots and three right slots. Your submission must pass the corrected design and fail the intentionally broken design before the testbench timeout. Have this simulation evidence ready before the October 20 teach-back.

---

## Part 5: Hardware Validation and Teach-Back
Once your testbench passes perfectly, deploy the standalone bring-up design to the Pico Dev-iCE. Hardware validation is required at the Lab 4 meeting; it is not an optional bonus for this lab.

1. Synthesize the standalone bring-up top from `ENGR433-Solutions/Lab_03` and generate `i2s_test.bin`.
2. Flash the bitstream to the FPGA.
3. Verify that BCK, WS, and I2S data are present on the assigned pins. Use an oscilloscope or logic analyzer to check the clock rates and edge relationship.
4. Confirm the LED heartbeat or another documented power-on indicator.
5. At the October 20 meeting, teach the design only after it is working: explain the clock divider, frame counter, shift-register alignment, and the testbench's injected failure, then demonstrate the working hardware. Lab 3 is not complete until the simulation passes, the intentionally broken design fails, and the hardware validation succeeds.

Audacity and the full USB audio path are optional extensions. The required hardware evidence is a working I2S clock/data bring-up and a clear explanation of the measured signals.

---

## 📝 Deliverables & Oral Defense
At your weekly 15-minute team meeting, you must provide:
1. **The Blueprint:** Your clock-tree diagram and a drawing showing the I2S bit-alignment.
2. **The Golden Vectors:** The provided reference files, with a brief explanation of the Python generator and any changes you made.
3. **The Simulation Proof:** Demonstrate your testbench catching an injected bit-shift error, and then passing the clean RTL.
4. **The AI Critique:** What did the AI mess up? Did it struggle with the falling-edge updates? Did it forget the 1-bit delay? 
5. **The Hardware Teach-Back:** At the Lab 4 meeting, demonstrate the I2S bring-up on the physical board and explain the measured BCK, WS, and data timing. Audacity is optional.

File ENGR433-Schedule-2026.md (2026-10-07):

# Digital Design Class Schedule: Autumn 2026
**Lecture:** Mon, Wed, Fri 1:00 – 1:50 p.m.
**Lab:** Tuesday 2:00 – 4:50 p.m.

*Note: There is no written homework for this course. You are expected to spend your 12 hours a week designing your blueprints, prompting the AI, writing your testbenches, and preparing for your Oral Defense. Lab 2 completion and demonstration are deferred because of the October 12-13 Senior Trip.*

| Week | Day | Date | Topic / Activity | Evaluation |
| :--: | :-: | :----- | :--- | :--- |
| **1**| M | Sep 28 | Course Intro, AI Workflow, & The Pico Dev-iCE | |
| | T | Sep 29 | **Lab 1: Hardware Design Review & Clock Budgets**| |
| | W | Sep 30 | Mixed-Signal Schematics & Power Domains | |
| | F | Oct 2  | Toolchain Setup: Icarus Verilog & GTKWave | |
| **2**| M | Oct 5  | Control Logic: FSMs in SystemVerilog | |
| | T | Oct 6  | **Lab 2: Traffic Light and AI Verification** | Lab 2 assigned; completion deferred |
| | W | Oct 7  | I2S Transmitter: Contract, Timing, and Testbench | Lab 3 assigned |
| | F | Oct 9  | Lab 3 Solution Walkthrough and Hardware Bring-up| |
| **3**| M | Oct 12 | Serial Protocols & Shift Registers | |
| | T | Oct 13 | ***Senior Trip — No Class or Lab*** | |
| | W | Oct 14 | Lab 2/3 Readiness Check; SPI Frames and Parser Introduction | Lab 2 ready for teach-and-demo; Lab 3 work plan |
| | F | Oct 16 | SPI Parser Architecture and Testbench Planning | Lab 2 teach-and-demo window |
| **4**| M | Oct 19 | Clock Domain Crossing (CDC) & Metastability | Lab 2 teach-and-demo window; Lab 3 final preparation |
| | T | Oct 20 | **Lab 4: SPI Command Parser** | Lab 2 final teach/demo; Lab 3 hardware validation and teach-back; Oral Defense L2 |
| | W | Oct 21 | ***Service Day — No Class*** | |
| | F | Oct 23 | Resolving CDC: Synchronizers and Handshakes | |
| **5**| M | Oct 26 | High-Speed I/O & Setup/Hold Times | |
| | T | Oct 27 | **Lab 5: ADC Capture and OTR Latch** | Oral Defense L4 |
| | W | Oct 28 | Asynchronous Event Catching & Pulse Stretching | |
| | F | Oct 30 | The Software Handshake: Pico SPI Runtime Control | |
| **6**| M | Nov 2  | Intro to DSP & Pipelined Datapaths | |
| | T | Nov 3  | **Lab 6: Numerically Controlled Oscillator (NCO)**| Oral Defense L5  |
| | W | Nov 4  | Phase Accumulators & Sine/Cosine Look-Up Tables  | |
| | F | Nov 6  | Signed vs. Unsigned Hardware Math (MSB Inversion)| |
| **7**| M | Nov 9  | Heterodyning & Quadrature Demodulation | |
| | T | Nov 10 | **Lab 7: Digital Mixer** | Oral Defense L6 |
| | W | Nov 11 | Two's Complement Multiplication & Bit Growth | |
| | F | Nov 13 | DSP Testbenches & Verifying Mixed Frequencies | |
| **8**| M | Nov 16 | Multi-Rate Signal Processing & Aliasing | |
| | T | Nov 17 | **Lab 8: CIC Decimation Filter** | Oral Defense L7 |
| | W | Nov 18 | Integrator Wrap-Around & The Hogenauer Rule | |
| | F | Nov 20 | Decimation Ratios & Process Gain Math | |
| **--**|**--**|**Nov 22-29**| ***Thanksgiving Break — No Classes*** | |
| **9**| M | Nov 30 | Structural Verilog & Top-Level Wrappers | |
| | T | Dec 1  | **Lab 9: System Integration** | Oral Defense L8 |
| | W | Dec 2  | Full-System Verification & Yosys Synthesis | |
| | F | Dec 4  | Troubleshooting Timing & Resource Limitations | |
| **10**| M  | Dec 7  | Intro to Mini-Projects (FIR, VNA, AM Demod) | |
| | T | Dec 8  | **Lab 10: Custom Mini-Project Implementation** | Oral Defense L9 |
| | W | Dec 9  | VNA Theory, OSL Calibration, & Sub-System Review | |
| | F | Dec 11 | Mini-Project Troubleshooting & Final Prep | |
| **11**| M-W| Dec 14-16| **Final Exams / Mini-Project Presentations** | Final Defense L10 |

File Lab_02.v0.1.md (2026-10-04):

# Lab 2: Control Logic, AI Verification, and the UK Traffic Light

**Objective:** This week, you will learn the "Edit-Simulate-Explain" loop. You will design Control Logic (a Finite State Machine), translate it into a strict AI prompt, and use AI to generate the SystemVerilog RTL. Before touching the hardware, you must write a self-checking testbench to mathematically prove the AI did not hallucinate the timing or the reset states.

## AI Use Policy
Chat-based AI is permitted for this lab. You may ask a chat AI for explanations, design suggestions, or code generated from your written blueprint. Agentic AI is not permitted: do not use coding agents, autonomous IDE modes, workspace agents, or tools that inspect or modify your files, run commands, or execute tests on your behalf. You must make the edits, run the simulations, inject the bug, and verify the results yourself, and you must be able to explain all submitted work.  Do not just put this lab into the AI as your prompt.

## Part 1: The British Traffic Light FSM
In the United States, traffic lights transition from Red, to Green, to Yellow. In the United Kingdom, traffic lights use an intermediate "Get Ready" state to alert drivers with manual transmissions to put their cars in gear. 

The UK Sequence is:
1. **Red** (Stop)
2. **Red + Amber** (Stop, but prepare to go)
3. **Green** (Go)
4. **Amber** (Stop if safe to do so)
5. **Red** (Stop)

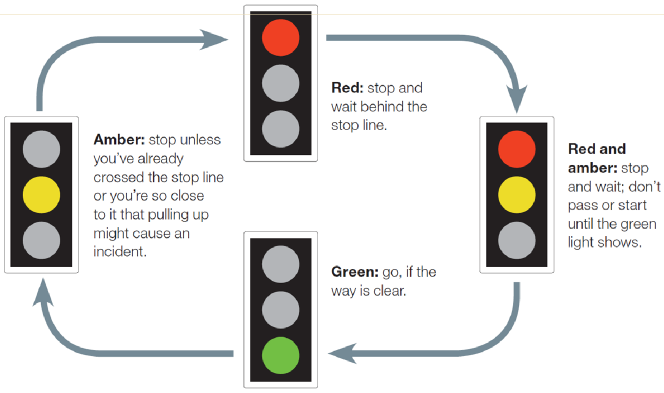
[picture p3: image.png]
Diagram of British traffic lights


*(Note: On our Pico Dev-iCE board, we will use the Yellow LED for Amber).*

### 1. The Hardware Constraints
Make a `ddc_sdr.pcf` file for the Pico Dev-iCE.  Look at your file. You have three RGB LED pins:
*   `RED` (Pin 39)
*   `YELLOW` (Pin 40)
*   `GREEN` (Pin 41)

**CRITICAL PHYSICS NOTE:** These pins are **Open-Drain**. They connect the LED cathode to Ground. Therefore:
*   Outputting `1'b0` turns the LED **ON**.
*   Outputting `1'b1` turns the LED **OFF** (High-Z).
*   This information comes from the iCE40 datasheet.

### 2. The Parameterized Clock
The Pico Dev-iCE master clock runs at **30.720 MHz**. If you simulate 5 seconds of real time at 30.72 MHz, your computer will simulate 153.6 million clock ticks, and your waveform viewer will likely crash.
*   Your module **must** use a `parameter TICKS_PER_SEC`.
*   In your testbench, you will override this parameter to a small number (e.g., `10`) so the simulation runs instantly. 
*   When compiling for the real hardware, it will default to `30720000`.

### 3. Your Task: The State Diagram
Before typing anything, draw a strict Finite State Machine (FSM) diagram on paper. 
*   Define the states (e.g., `ST_RED`, `ST_RED_YEL`, etc.).
*   Define the duration of each state (e.g., Red = 3 seconds, Red+Yel = 1 second, Green = 3 seconds, Yel = 1 second).
*   Define the exact 3-bit LED output for each state. 

---

## Part 2: The AI Prompt (The Blueprint)

Large Language Models (like Claude, Gemini, or Windsurf) are terrible at inventing hardware architecture, but they are flawless typists. You must give the AI your exact FSM blueprint.

Use the following template to prompt your AI. **Fill in the bracketed information with the data from your paper diagram.**

> **SystemVerilog FSM Generation Request**
> Act as a Senior ASIC Verification Engineer. Write a SystemVerilog module for a UK Traffic Light controller. Use a standard multi-always-block FSM architecture with `typedef enum logic`.
> 
> **Parameters:** 
> * `TICKS_PER_SEC` (default 30720000)
> 
> **Inputs:** `clk`, `reset_n` (Active Low)
> **Outputs:** `led_red`, `led_yel`, `led_grn` (Active Low: 0 = ON, 1 = OFF).
> 
> **Internal Timer:** Include a counter that increments every clock cycle to track seconds based on `TICKS_PER_SEC`. 
> 
> **States:**
> 1. `ST_RED`:
>     * Outputs: [Your LED bits]
>     * Wait for [X] seconds, then go to `ST_RED_YEL`.
> 2. `ST_RED_YEL`:
>     * Outputs: [Your LED bits]
>     * Wait for [X] seconds, then go to `ST_GRN`.
> 3. `ST_GRN`:
>    ... [Continue defining the rest of your states]
> 
> **Reset Behavior:** Asynchronous active-low reset. The system must default to `ST_RED` and clear the timer.

---

## Part 3: The Self-Checking Testbench

You must not trust the AI. You must prove it works mathematically. Write a testbench (`traffic_tb.sv`) that does the following:

1.  **Override the Parameter:** Instantiate your module, overriding `TICKS_PER_SEC` to `10`. 
2.  **Generate the Clock:** Write an `always` block to toggle the clock every 5 time units.
3.  **The Self-Checking Monitor:** Write code that counts the clock ticks and uses `assert` or `if/else` statements to verify the outputs.
    *   *Example Check:* "If the reset is released, and we wait exactly 10 clock ticks, does the state transition from RED to RED_YEL? If not, `$display("FAIL")` and `$stop`."
4.  **Inject a Bug:** Purposely modify the AI's RTL (e.g., change the RED_YEL timer from 1 second to 2 seconds, or change an LED output to active-high). Run the testbench and prove that your testbench catches the error and halts.

---

## Part 4: Synthesis & Hardware Bring-Up

Once your testbench prints a clean "PASS" across all states, it is time to build the real hardware.

1.  Use the OSS CAD Suite tools (`yosys`, `nextpnr-ice40`, `icepack`) to synthesize your `.sv` file against the `ddc_sdr.pcf` constraints file. 
2.  Generate your `traffic.bin` bitstream.
3.  Load the bitstream onto the Pico using the MicroPython script from Lab 1.
4.  Watch the LEDs on the Pico Dev-iCE board. If they sequence properly, your physical timing matches your simulated timing!

---

## 📝 Deliverables & Oral Defense

At your weekly team meeting with the instructor, you must provide:

1. **The Blueprint:** Your hand-drawn FSM State Diagram, including timers and output vectors.
2. **The Prompt Log:** The exact prompt you fed to the AI.
3. **The AI Critique:** Identify one thing the AI did poorly (e.g., did it use an inefficient single-always block? Did it mess up the active-low logic? Did it have an off-by-one error on the counter?).
4. **The Simulation Proof:** Demonstrate your self-checking testbench running in the terminal. Show the output catching your injected bug, and then show it passing the corrected RTL.
5. **The Hardware Demo:** Show the physical board successfully running the UK traffic light sequence.
6. **Your goal:** is to teach your professor this material.  He may want to do it by hand without AI.

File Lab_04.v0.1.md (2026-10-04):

Here is the complete **Lab 4 Document** for your students. It perfectly implements the `ddc_protocol.h` C-header you provided and introduces them to one of the most critical concepts in modern digital design: **Clock Domain Crossing (CDC)**.

This lab ensures they write bulletproof verification that catches corrupted frames and aborted communications *before* those errors can crash the radio's DSP math.

You can save this as `Lab_04_SPI_Parser.md` in your repository!

***

# Lab 4: The SPI Command Parser & Clock Domain Crossing (CDC)

**Objective:** This week, you will build the Control Interface for your radio. The Raspberry Pi Pico will act as the SPI Master, sending tuning and control commands to the FPGA. You will learn how to design a serial parsing FSM, how to handle Little-Endian byte ordering, and how to safely transfer data between two different clock speeds using Clock Domain Crossing (CDC) synchronization.

## AI Use Policy
Chat-based AI is permitted for this lab. You may ask a chat AI for explanations, design suggestions, or code generated from your written blueprint. Agentic AI is not permitted: do not use coding agents, autonomous IDE modes, workspace agents, or tools that inspect or modify your files, run commands, or execute tests on your behalf. You must make the edits, run the simulations, test the malformed frames, and verify the results yourself, and you must be able to explain all submitted work.

## Part 1: The Hardware Contract & The CRAM Paradox
As discussed in Lab 1, the Pico uses its hardware `SPI0` block to blast the bitstream into the FPGA's CRAM during boot, and reuses those exact same wires during runtime. 

Because the Pico is driving the bus, you must write your Verilog from the perspective of an **SPI Slave**:
*   **`spi_sck` / `ICE_SCK` (FPGA Pin 15):** The SPI Clock, driven by the Pico.
*   **`spi_csn` / `ICE_SSN` (FPGA Pin 16):** Active-low Chip Select, driven by the Pico.
*   **`spi_mosi` / `SPI0_TX` / `ICE_SO` (FPGA Pin 17):** Master Out, Slave In. Configure this as an **INPUT**.
*   **`spi_miso` / `SPI0_RX` / `ICE_SI` (FPGA Pin 14):** Master In, Slave Out. Configure this as an **OUTPUT**.

The current SDK runtime transfer is nominally 33 MHz, uses SPI mode 0, and
sends bits MSB-first. The FPGA samples MOSI on each rising edge of `spi_sck`;
the Pico changes MOSI on the falling edge.

## Part 2: The `ddc_protocol.h` Frame Format
To prevent the FPGA from acting on garbage data or static, the Pico wraps every command in a strict 8-byte (64-bit) protocol frame. 

Every time the Pico pulls `ICE_SSN` LOW, it will transmit exactly 8 bytes:
1.  **Byte 0 (Sync):** `0xD5`
2.  **Byte 1 (Version):** `0x01`
3.  **Byte 2 (Command):** e.g., `0x01` (Set Freq), `0x02` (Set Rate), `0x04` (Clear OTR).
4.  **Byte 3 (Length):** `0x04` (Indicating a 4-byte payload follows).
5.  **Bytes 4, 5, 6, 7 (Payload):** A 32-bit value in **Little-Endian** format. (Byte 4 is the Least Significant Byte; Byte 7 is the Most Significant Byte).

*Rule: If `ICE_SSN` goes HIGH before all 64 bits are received, or if the Sync/Version/Length bytes do not match the expected values exactly, the FPGA must discard the frame and do nothing.*

## Part 3: The Danger of Clock Domain Crossing (CDC)
The SPI Clock (`ICE_SCK`) comes in bursts from the Pico and the current SDK runtime clock is nominally 33 MHz. Your DSP radio logic runs continuously on a completely separate 30.72 MHz master clock.

If you wire the output of an SPI shift register directly to your DSP logic, the 30.72 MHz clock might try to read the 32-bit value while the SPI clock is changing it. You can read a mixture of the old and new frequency, tearing the data and corrupting the radio control state.

**The Mailbox / Handshake Solution:**
1.  **The SPI Domain (`always @(posedge spi_sck)`):** Shift the incoming bits into a temporary register. If all 8 bytes are valid and `spi_csn` stays LOW through the eighth byte, copy the command and value into a held shadow register and toggle a `spi_commit_flag`. A rising `spi_csn` asynchronously abandons a partial frame.
2.  **The Master Domain (`always @(posedge clk_30m)`):** Pass the commit toggle through a **2-Flop Synchronizer** and detect a change. The shadow bus remains unchanged while the toggle crosses, so the 30.72 MHz domain copies a complete command only after the bundled data has settled. A synchronizer reduces metastability risk for the toggle; it does not make arbitrary unsynchronized buses safe.

---

## Part 4: The AI Prompt (The Blueprint)

Before prompting the AI, draw the FSM for the SPI parser on a whiteboard. Map out the `WAIT_SYNC` ➔ `CHECK_VER` ➔ `GET_CMD` states. Once you understand the flow, use this template:

> **SystemVerilog SPI Parser & CDC Request**
> Act as a Senior ASIC Designer. Write a SystemVerilog SPI Slave that parses a specific 64-bit command frame and safely crosses the data into a 30.72 MHz clock domain.
> 
> **Inputs:** `clk_30m`, `reset_n`, `spi_sck`, `spi_csn`, `spi_mosi`
> **Outputs:** `spi_miso`, `cmd_freq_valid`, `cmd_freq_val[31:0]`, `cmd_rate_valid`, `cmd_rate_val[31:0]`, `cmd_clear_otr`
> 
> **Clock Domain 1: SPI Parser (`posedge spi_sck`)**
> *   When `spi_csn` is LOW, shift data in from `spi_mosi` (MSB-first per byte). 
> *   The frame is 8 bytes: `Sync (0xD5)`, `Version (0x01)`, `Command`, `Length (0x04)`, and a 32-bit `Value` (Little-Endian).
> *   Use an FSM or separate bit/byte counters. If the Sync, Version, or Length do not match exactly, consume and discard the frame. If `spi_csn` rises before byte 7 completes, discard the frame and reset the parser for the next transaction.
> *   If the frame is valid and complete, store the parsed Command and 32-bit Value in a shadow register, and toggle a `spi_commit_flag`.
> 
> **Clock Domain 2: The Master Domain (`posedge clk_30m`)**
> *   Pass the `spi_commit_flag` through a 2-stage flip-flop synchronizer and detect a change.
> *   When an edge is detected, read the held shadow register. Do not read a shadow bus while the SPI parser is still updating it.
> *   If Command == `0x01`, output the 32-bit value to `cmd_freq_val` and pulse `cmd_freq_valid` for one clock cycle.
> *   If Command == `0x02`, output the value to `cmd_rate_val` and pulse `cmd_rate_valid` for one clock cycle.
> *   If Command == `0x04`, pulse the `cmd_clear_otr` output for one clock cycle. 

---

## Part 5: The Self-Checking Testbench (Negative Testing)

This is the most critical verification week of the course. You must write a testbench (`spi_parser_tb.v`) that acts as the Pico and deliberately tries to break your FPGA.

Your testbench must simulate the 30.72 MHz clock and the asynchronous SPI clock. Write a `task send_spi_byte(input [7:0] data)` to make generating frames easier.

**Your testbench MUST check for the following failures:**
1.  **The Happy Path:** Send `D5 01 01 04 00 00 00 00` (Set Frequency to 0). Verify that `cmd_freq_valid` pulses on the 30 MHz clock. 
2.  **The Bad Sync:** Send `AA 01 01 04...`. Verify the module completely ignores it.
3.  **Bad Header Fields:** Send a bad version and a bad length. Verify neither produces a command pulse.
4.  **The Aborted Frame (Torn Data):** Send a valid sync and command, but pull `spi_csn` HIGH after only 6 bytes. Verify the module drops the data and does **not** update the output registers.
5.  **Endianness Check:** Send a frequency command with payload `0x78 0x56 0x34 0x12`. Assert that the 30 MHz domain outputs exactly `32'h12345678`.
6.  **Other Commands:** Verify the sample-rate command and the clear-OTR command produce their own one-cycle outputs.
7.  **Back-to-Back Frames:** Send two valid frames in consecutive chip-select transactions and verify each commits exactly once.

---

## Part 6: Hardware Bring-Up

Once your testbench prints "PASS" for all edge cases, synthesize the code. 
We will test it on the board using the provided Pico firmware.

1.  Flash your generated bitstream (`spi_test.bin`) into the FPGA CRAM.
2.  Flash the current C SDR firmware from `Software/ddc_sdr_firmware` onto your Pico.
3.  *Temporary Debug Code:* Route `cmd_freq_val[0]` to `GREEN`, bit 1 to `YELLOW`, and bit 2 to `RED`. The standalone solution exposes these logical LED outputs.
4.  Open your serial terminal to the Pico and send the CDC text command `FREQ,1`. The Green LED should light up. Send `FREQ,7`. All three LEDs should light up. 

If the LEDs match your commands, your SPI FSM and Clock Domain Crossing are flawlessly passing data at hardware speeds!

---

## 📝 Deliverables & Oral Defense
At your weekly 15-minute team meeting, you must provide:
1. **The Blueprint:** Your FSM diagram or Shift-Register architecture drawing.
2. **The Endianness Math:** Explain manually how `0x78 0x56 0x34 0x12` becomes `32'h12345678`.
3. **The Simulation Proof:** Demonstrate your testbench safely ignoring the aborted CS frame, and show the exact clock cycle where the 2-flop synchronizer passes the valid data.
4. **The Hardware Demo:** Send frequency commands via the Pico's serial terminal and show the FPGA LEDs reacting instantly to the payload.

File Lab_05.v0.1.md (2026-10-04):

# Lab 5: ADC Capture & The OTR Sticky Status Register

**Objective:** This week, you will register the high-speed ADC bus in the
30.720 MHz FPGA domain and build a clocked sticky OTR status register. The
sticky status is a hardware-to-software handshake between the FPGA and the
Pico.

## AI Use Policy
Chat-based AI is permitted for this lab. You may ask a chat AI for explanations, design suggestions, or code generated from your written blueprint. Agentic AI is not permitted: do not use coding agents, autonomous IDE modes, workspace agents, or tools that inspect or modify your files, run commands, or execute tests on your behalf. You must make the edits, run the simulations, test the edge cases, and verify the results yourself, and you must be able to explain all submitted work.

## Part 1: The Hardware Contract
The MS9280 is a 32 MSPS, 8-bit Analog-to-Digital Converter.
*   **The Clock (`adc_clk`, FPGA pin 23):** The FPGA forwards the 30.720 MHz master clock to the ADC.
*   **The Data (`adc_data[7:0]`, FPGA pins 25, 26, 27, 28, 31, 32, 34, 35):** The ADC outputs 8 bits of data.
*   **The Out-of-Range Pin (`adc_otr`, FPGA pin 36):** If the analog radio signal exceeds the ADC's voltage limits (clipping), the ADC asserts the OTR input HIGH.
*   **The Pico interrupt (`fpga_int`, FPGA pin 13):** The FPGA holds this active-high output until a valid clear command arrives.

**The Timing Trap:**
Because the ADC sits away from the FPGA, the ADC clock, output delay, board
skew, and FPGA input setup/hold time all matter. Register `adc_data[7:0]` and
`adc_otr` on the 30.720 MHz capture edge before using them in DSP logic. This
lab models the inputs as stable around that edge; it does not replace timing
constraints or hardware timing validation.

## Part 2: The Sticky Status Protocol (System Architecture)
The interface uses a **Deterministic Handshake** rather than a fixed-duration
pulse stretcher.
According to `ddc_protocol.h`, the system handles clipping like this:
1.  A massive radio signal causes the ADC to assert `OTR` HIGH for one sample-clock period, approximately 32.55 ns at 30.720 MHz.
2.  The FPGA catches this synchronously and sets a **sticky status register**. It drives the `FPGA_INT` pin HIGH and keeps it HIGH until cleared.
3.  The Pico sees `FPGA_INT` go HIGH. It knows the radio is clipping.
4.  The Pico steps up the PGA attenuation to turn down the analog volume. 
5.  The Pico sends SPI Command `0x04` (`DDC_FPGA_CMD_CLEAR_OTR`) to the FPGA.
6.  Your SPI Parser (from Lab 4) generates a `cmd_clear_otr` pulse. 
7.  The FPGA sees this clear pulse and forces `FPGA_INT` back LOW, unless `OTR` is also HIGH on that same edge. OTR has priority so an active clipping event cannot be cleared accidentally.

---

## Part 3: The AI Prompt (The Blueprint)

Before prompting the AI, map out your module. It has two simple jobs: an
8-bit capture register for the data, and a clocked sticky status register for
the `OTR` interrupt. This is not a level-sensitive SR latch; all state changes
occur on `clk_30m` edges, with asynchronous reset only.

Use this template to generate your RTL:

> **SystemVerilog ADC Capture & OTR Sticky-Register Request**
> Act as a Senior ASIC Designer. Write a SystemVerilog module that captures a high-speed ADC bus and implements a sticky interrupt register. Normal state changes must occur synchronously to `clk_30m`; use an active-low asynchronous reset.
> 
> **Inputs:** 
> *   `clk_30m`, `reset_n`
> *   `adc_data_in[7:0]` (Raw pins from the ADC)
> *   `adc_otr_in` (Raw pin from the ADC)
> *   `cmd_clear_otr` (1-clock-cycle pulse from the SPI Parser)
> 
> **Outputs:** 
> *   `adc_clk` (30.720 MHz clock forwarded to the ADC)
> *   `adc_data_out[7:0]` (Registered, safe data for the DSP mixer)
> *   `fpga_int` (The sticky interrupt status to the Pico)
> 
> **Architecture:**
> 1.  **Data Capture:** On every positive edge of `clk_30m`, register `adc_data_in` into `adc_data_out`.
> 2.  **The Sticky Status Register (`fpga_int`):**
>     *   If `adc_otr_in` is HIGH, set `fpga_int` HIGH.
>     *   Else if `cmd_clear_otr` is HIGH, set `fpga_int` LOW.
>     *   Otherwise, `fpga_int` holds its current state.
>     *   *Priority Note:* If `adc_otr_in` and `cmd_clear_otr` happen on the exact same clock cycle, `adc_otr_in` wins (the status stays HIGH because clipping is still occurring).

---

## Part 4: The Self-Checking Testbench (Edge Cases)

An interrupt status register that drops events or clears incorrectly will break
the radio's Automatic Gain Control (AGC). Your testbench
(`adc_capture_tb.sv`) must test the edge cases.

**Your testbench MUST check and print "PASS" for the following:**
1.  **The 1-Cycle Catch:** Assert `adc_otr_in` for exactly ONE 30.72 MHz clock cycle, then pull it LOW. Assert that `fpga_int` goes HIGH and stays HIGH for at least 50 clock cycles.
2.  **The Clear:** Assert `cmd_clear_otr` for one clock cycle. Assert that `fpga_int` drops LOW on the next clock. 
3.  **The Collision (Priority Check):** Assert both `adc_otr_in` AND `cmd_clear_otr` on the exact same clock edge. Assert that `fpga_int` evaluates to HIGH. (If it goes LOW, your radio will ignore active clipping!)
4.  **Data Alignment:** Feed a ramp sequence into `adc_data_in` (`0x01`, `0x02`, `0x03`). Assert that `adc_data_out` outputs the exact same ramp, delayed by exactly one clock cycle.

---

## Part 5: Hardware Bring-Up & The AGC Handshake

This week, you will wire Lab 4 (the SPI parser) and Lab 5 (the ADC capture)
together in a top-level wrapper.

1.  Connect your SPI Parser's `cmd_clear_otr` output to this new module's clear input. 
2.  Synthesize your bitstream (`adc_test.bin`) and flash the FPGA.
3.  Flash the current C SDR firmware from `Software/ddc_sdr_firmware` to the Pico.
4.  Open your serial terminal to the Pico to view the debug logs.

**The Hardware Test:**
*   *Warning: Do not short ADC or analog-input pins to power or ground.*
*   Do not use body contact, a screwdriver, or an unspecified 3.0 V peak-to-peak source as a trigger. If a physical test is approved, use a current-limited, documented signal-generator level within the ADC and analog-front-end limits, and verify it with an oscilloscope before connecting it.
*   Probe `fpga_int` with a logic analyzer or oscilloscope. When the ADC clips, the Pico should observe the active-high interrupt, step the PGA hardware mask through its verified states (`0x0 -> 0x1 -> 0x3 -> 0xF`), and send command `0x04` to clear the sticky status.

If the Pico climbs to `0xF` (Maximum Attenuation), your hardware handshake is functioning perfectly!

---

## 📝 Deliverables & Oral Defense
At your weekly 15-minute team meeting, you must provide:
1. **The Blueprint:** Your block diagram showing the data path and the clocked sticky-register logic.
2. **The Timing Diagram:** Draw the exact clock-by-clock timing of the Collision edge-case. 
3. **The Simulation Proof:** Demonstrate your testbench catching a broken priority state, and then show it passing the corrected RTL.
4. **The AI Critique:** How did the AI handle the priority collision between Set and Reset? Did it use an `if/else` block, or did it try to use combinational logic? Why is an `always_ff` block required here?
5. **The Hardware Demo:** Show `fpga_int` asserting on a controlled overload and the Pico clearing it after the PGA response. A serial log alone is not sufficient evidence of the FPGA pin timing.

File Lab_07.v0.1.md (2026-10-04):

# Lab 7: The Digital Mixer (Quadrature Demodulation)

**Objective:** This week, you will build the mathematical heart of the radio. You will take the raw RF signals from the ADC and multiply them by the Sine and Cosine waves from your NCO. This process (Heterodyning) shifts the high-frequency radio station down to 0 Hz (Baseband). You will learn how to handle bit-growth, Signed vs. Unsigned arithmetic, and pipelined multiplication.
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

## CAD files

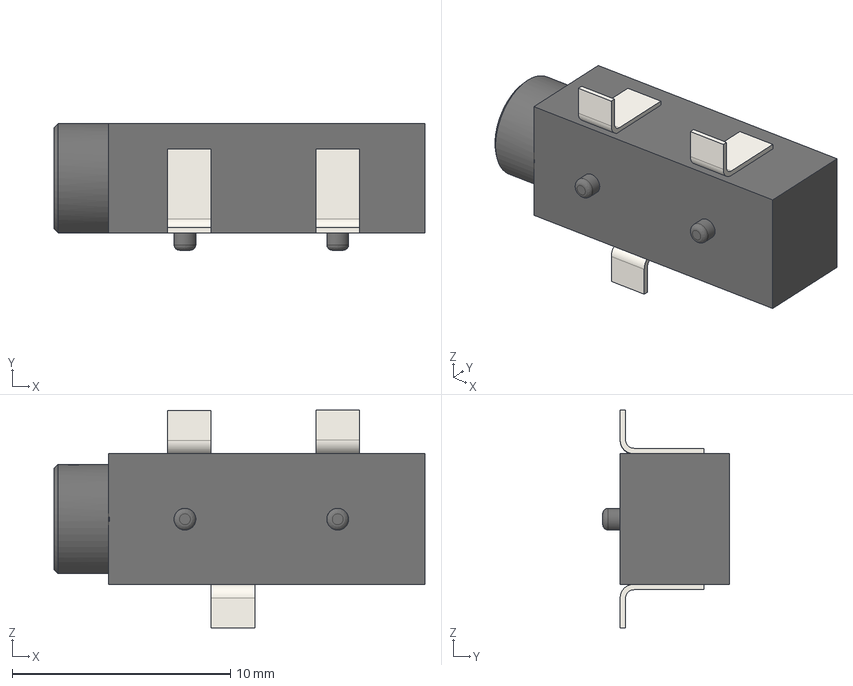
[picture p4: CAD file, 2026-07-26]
Hardware/audio_jack.step
17.0 x 5.80 x 9.98 mm
sj-3524-smt-tr-pi v1 x 2
BB x 2
sj-3524-smt-tr-pi v003
sj-3524-smt-tr-pi v004 x 2

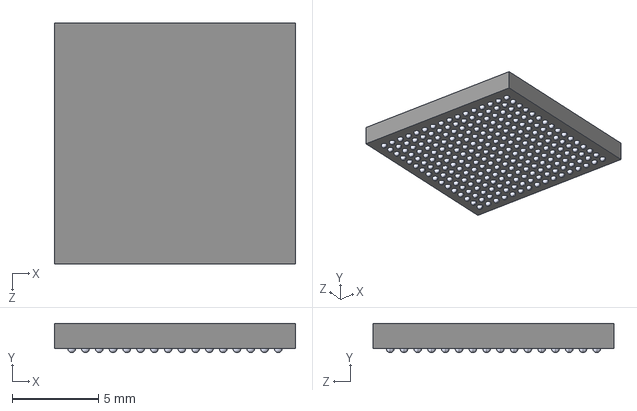
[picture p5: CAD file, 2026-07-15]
Hardware/LFE5U-25F-6BG256C/LFE5U-25F-6BG256C.step
14.0 x 1.70 x 14.0 mm

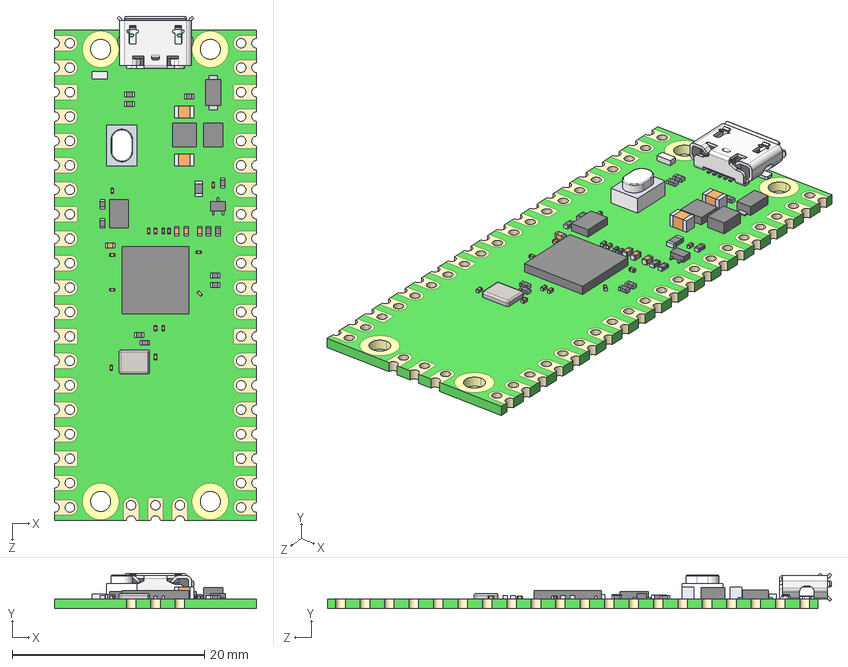
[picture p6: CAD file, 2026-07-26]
Hardware/Raspberry Pi Pico-R3.STEP
21.0 x 3.69 x 52.4 mm
PCB, Raspberry Pi Pico-R3
MicroUSB Port, Raspberry Pi Pico-R3
RP2040 Microcontroller, Raspberry Pi Pico-R3
SW1, Tact Switch, Raspberry Pi Pico-R3
D1, Diode, Schottky, Raspberry Pi Pico-R3
D2, QSME-C194, LED, Raspberry Pi Pico-R3
L1, Inductor, Raspberry Pi Pico-R3
U2, RT6150B-33GQW, Buck Boost Converter, Raspberry Pi Pico-R3
U3, W25Q16JVUXIQ, Serial NOR Flash 16 Mbit, Raspberry Pi Pico-R3
Q1, MOSFET, DMG1012T, Raspberry Pi Pico-R3
X1, X12M000000S096, 12 Mhz Crystal Resonator, Raspberry Pi Pico-R3
SMD Resistor, Configurable, Raspberry Pi Pico-R3_R1
SMD Resistor, Configurable, Raspberry Pi Pico-R3_R2
SMD Resistor, Configurable, Raspberry Pi Pico-R3_R3
SMD Resistor, Configurable, Raspberry Pi Pico-R3_R4
SMD Resistor, Configurable, Raspberry Pi Pico-R3_R5
SMD Resistor, Configurable, Raspberry Pi Pico-R3_R6
SMD Resistor, Configurable, Raspberry Pi Pico-R3_R7
SMD Resistor, Configurable, Raspberry Pi Pico-R3_R8
SMD Resistor, Configurable, Raspberry Pi Pico-R3_R9
SMD Resistor, Configurable, Raspberry Pi Pico-R3_R10
SMD Resistor, Configurable, Raspberry Pi Pico-R3_R11
SMD Resistor, Configurable, Raspberry Pi Pico-R3_R12
SMD Resistor, Configurable, Raspberry Pi Pico-R3_R13
SMD Resistor, Configurable, Raspberry Pi Pico-R3_R14
SMD Resistor, Configurable, Raspberry Pi Pico-R3_R15
SMD Capacitor, Configurable, Raspberry Pi Pico-R3_C1
SMD Capacitor, Configurable, Raspberry Pi Pico-R3_C2
SMD Capacitor, Configurable, Raspberry Pi Pico-R3_C3
SMD Capacitor, Configurable, Raspberry Pi Pico-R3_C4
SMD Capacitor, Configurable, Raspberry Pi Pico-R3_C5
SMD Capacitor, Configurable, Raspberry Pi Pico-R3_C6
SMD Capacitor, Configurable, Raspberry Pi Pico-R3_C7
SMD Capacitor, Configurable, Raspberry Pi Pico-R3_C8
SMD Capacitor, Configurable, Raspberry Pi Pico-R3_C9
SMD Capacitor, Configurable, Raspberry Pi Pico-R3_C10
SMD Capacitor, Configurable, Raspberry Pi Pico-R3_C11
SMD Capacitor, Configurable, Raspberry Pi Pico-R3_C12
SMD Capacitor, Configurable, Raspberry Pi Pico-R3_C13
SMD Capacitor, Configurable, Raspberry Pi Pico-R3_C14
SMD Capacitor, Configurable, Raspberry Pi Pico-R3_C15
SMD Capacitor, Configurable, Raspberry Pi Pico-R3_C16
SMD Capacitor, Configurable, Raspberry Pi Pico-R3_C17
SMD Capacitor, Configurable, Raspberry Pi Pico-R3_C18

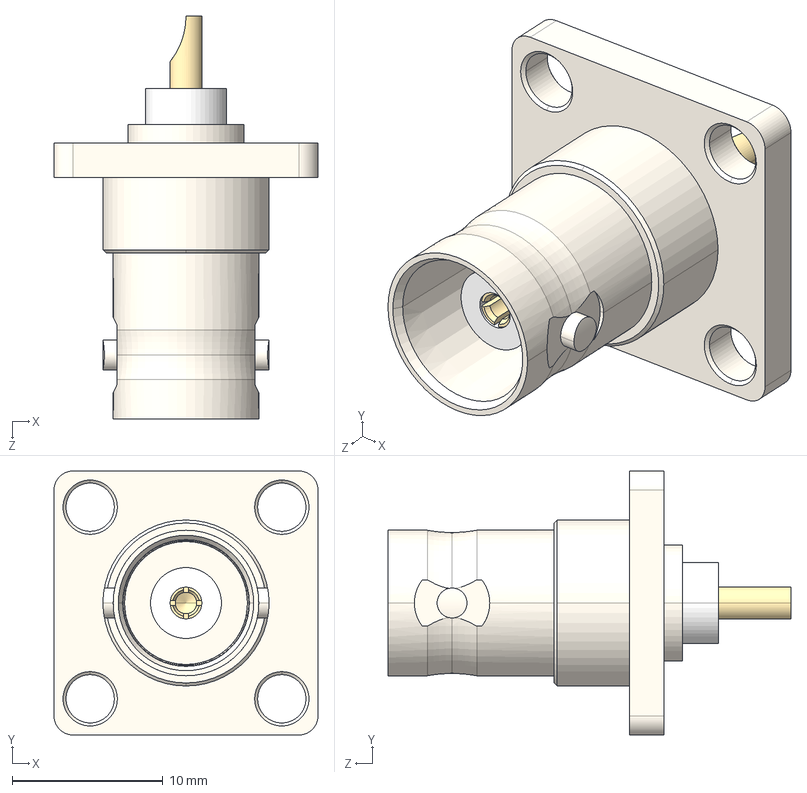
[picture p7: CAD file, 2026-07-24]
Hardware/Connecteur BNC Amphenol RF Femelle Droit.STEP
17.5 x 17.5 x 26.7 mm

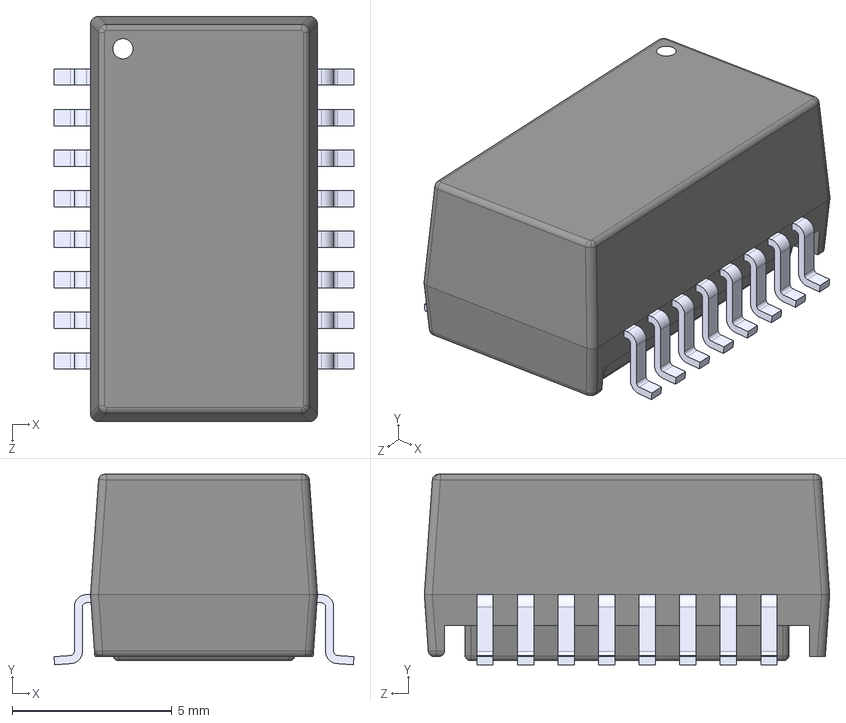
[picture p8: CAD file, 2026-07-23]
Hardware/H1102NLT.step
9.40 x 5.97 x 12.7 mm

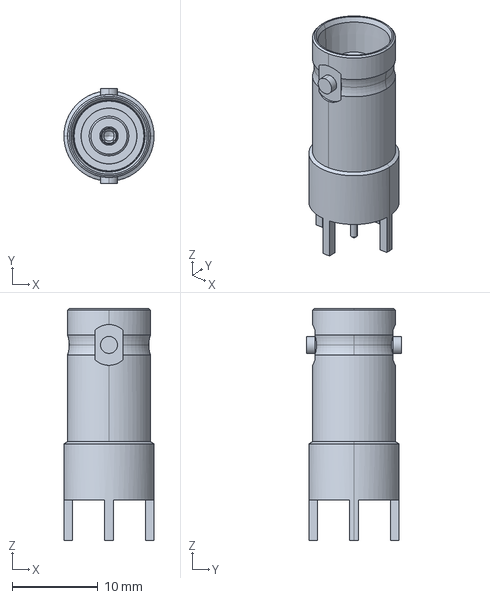
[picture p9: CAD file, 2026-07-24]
Hardware/731000133.stp
10.5 x 11.0 x 27.0 mm

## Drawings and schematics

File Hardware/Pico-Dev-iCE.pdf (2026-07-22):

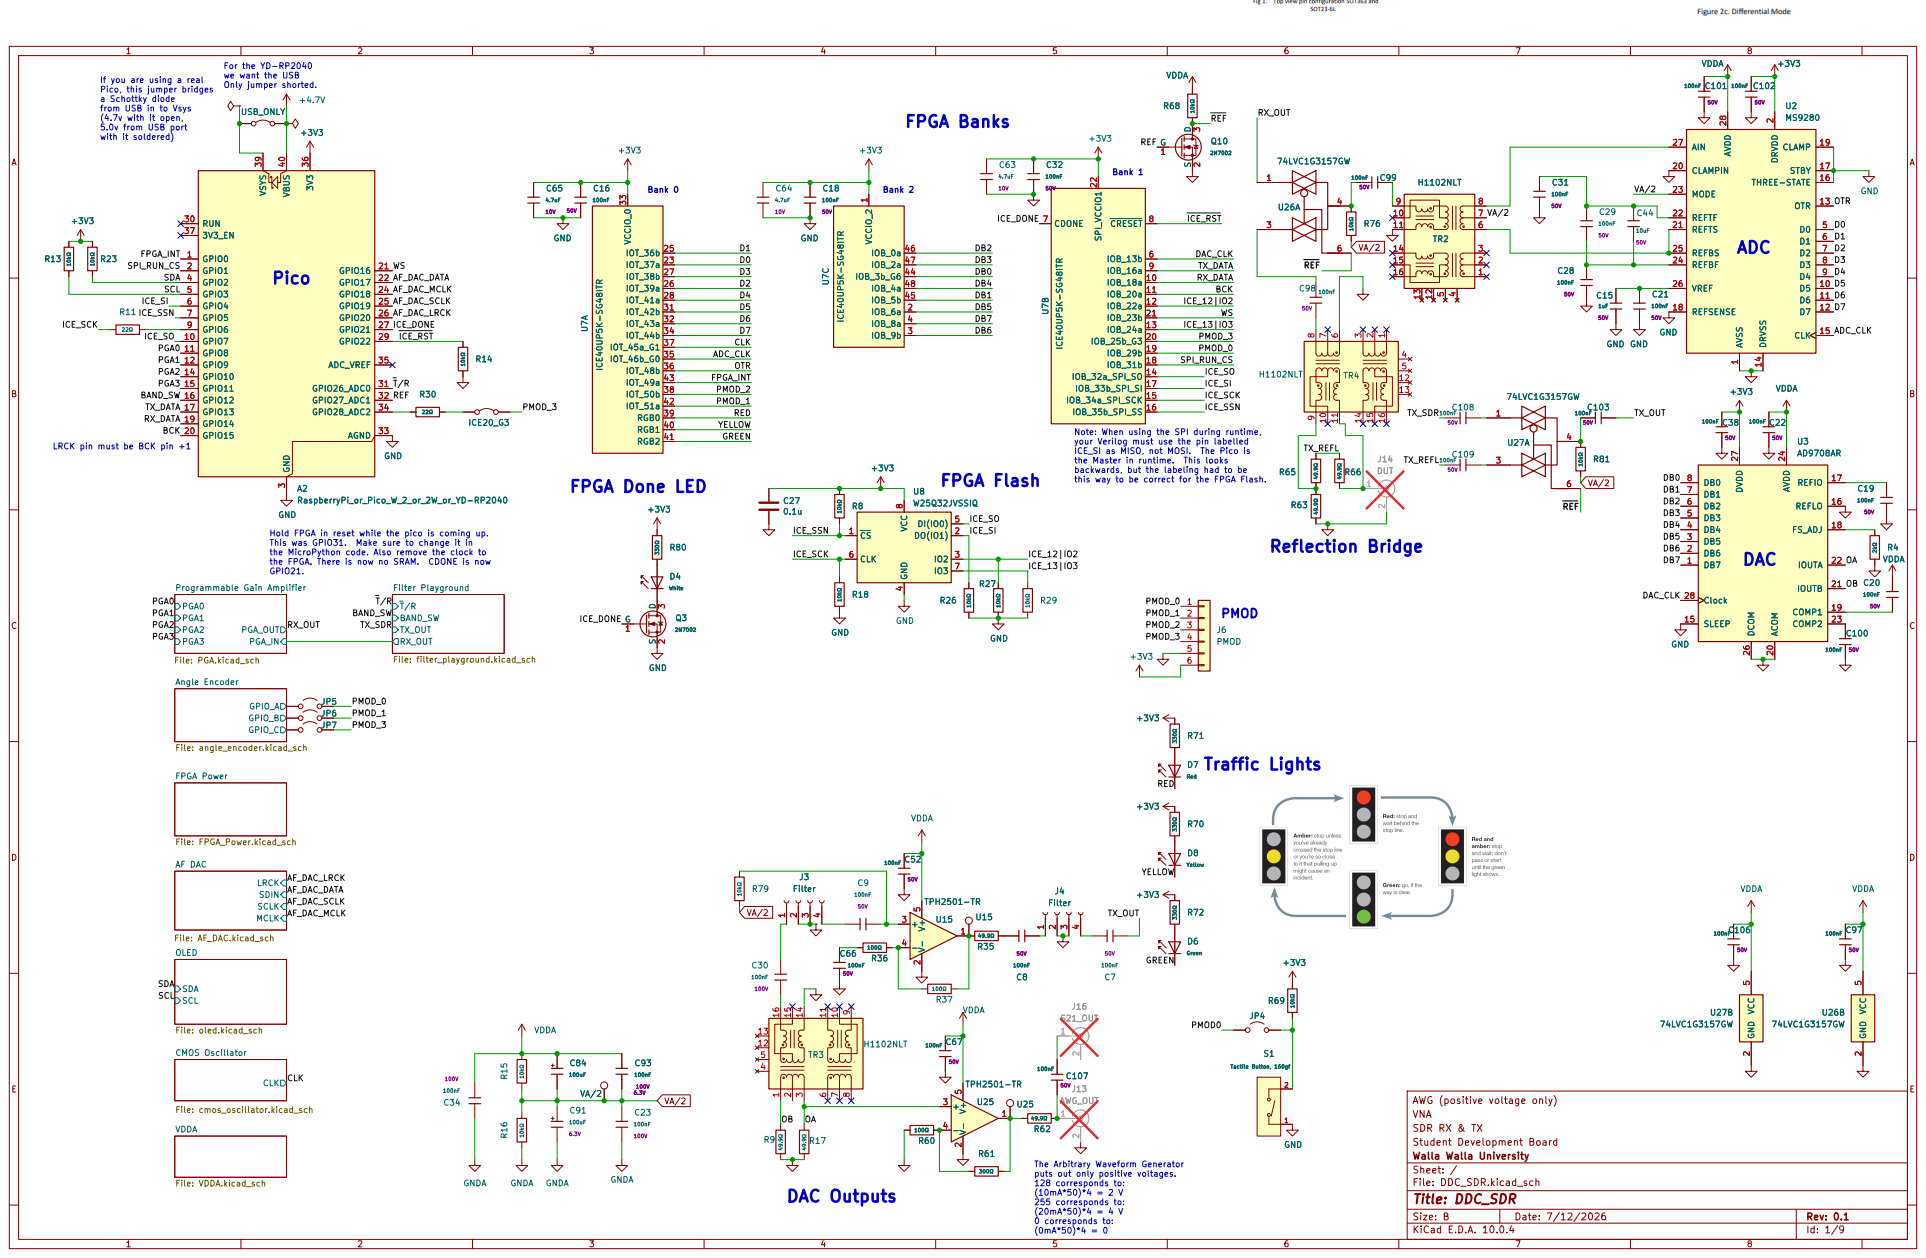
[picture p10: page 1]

If you are using a real Pico, this jumper bridges a Schottky diode

from USB in to Vsys

PGA_OUT Programmable Gain Amplifier File: PGA.kicad_sch CLK

the MicroPython code. Also remove the clock to

File: AF_DAC.kicad_sch
AWG (positive voltage only) SCL SDA OLED

The Arbitrary Waveform Generator puts out only positive voltages. 128 corresponds to: (10mA*50)*4 = 2 V 255 corresponds to: (20mA*50)*4 = 4 V 0 corresponds to: (0mA*50)*4 = 0

Size: B | Rev: 0.1
KiCad E.D.A. 10.0.4 | Id: 1/9

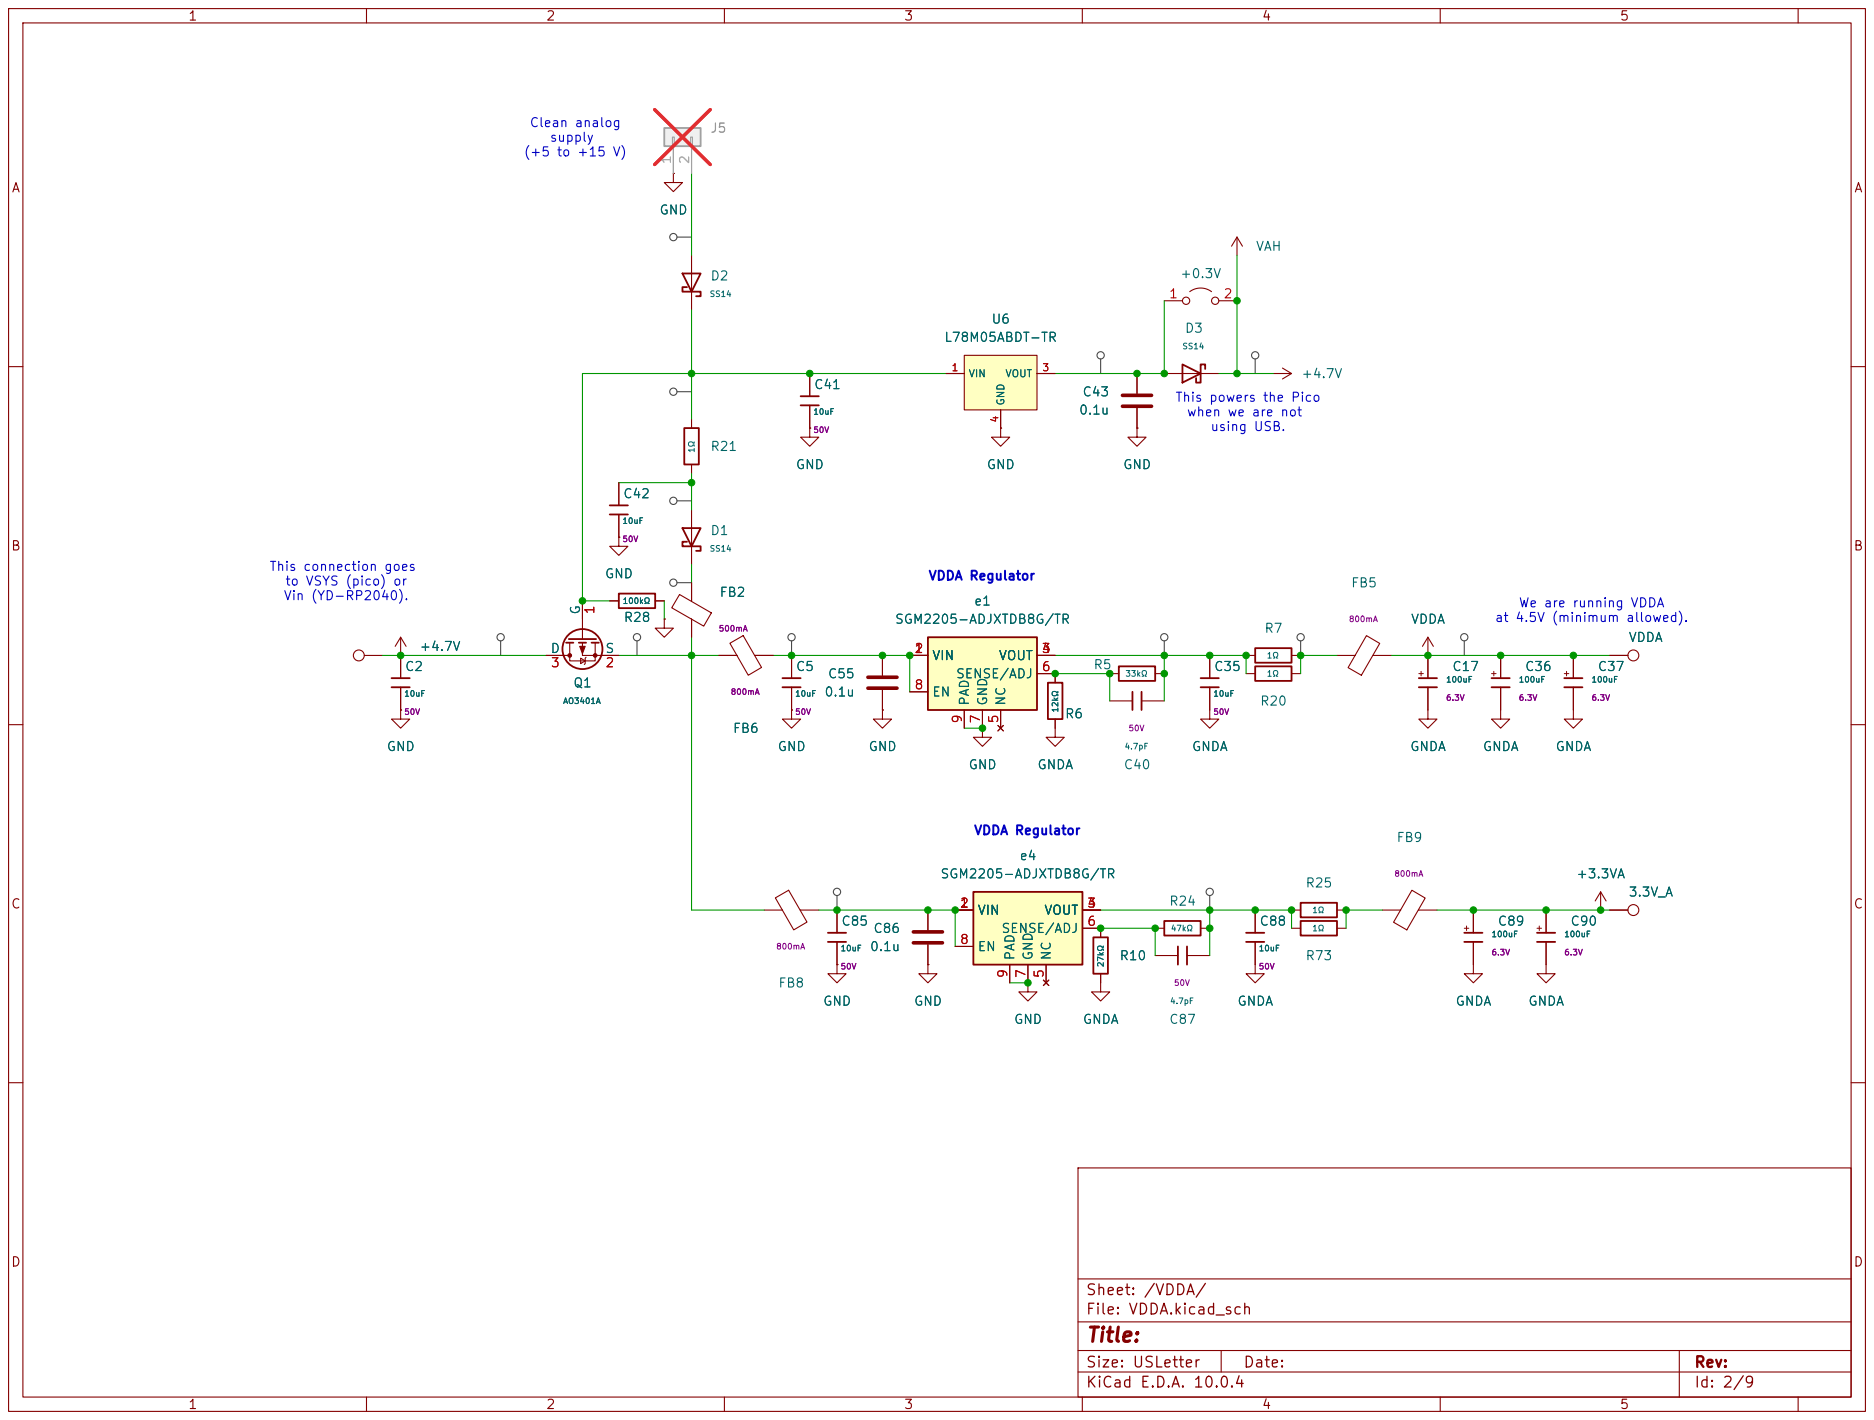
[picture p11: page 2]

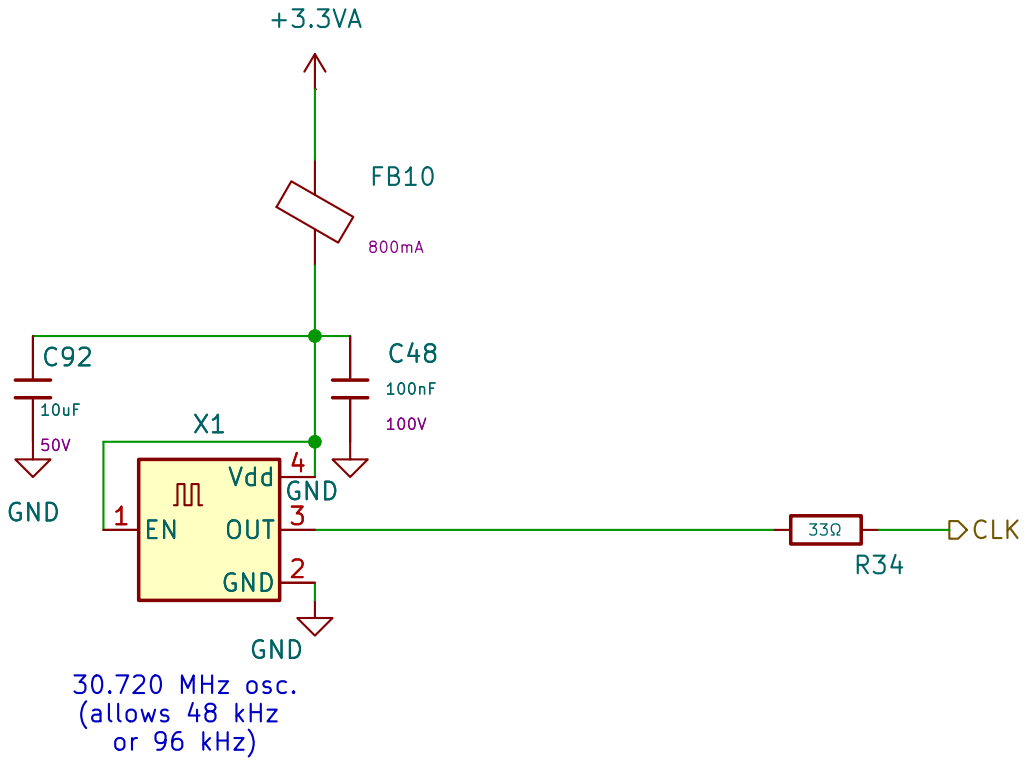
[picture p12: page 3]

10uF 50V GND
30.720 MHz osc. (allows 48 kHz or 96 kHz) X1

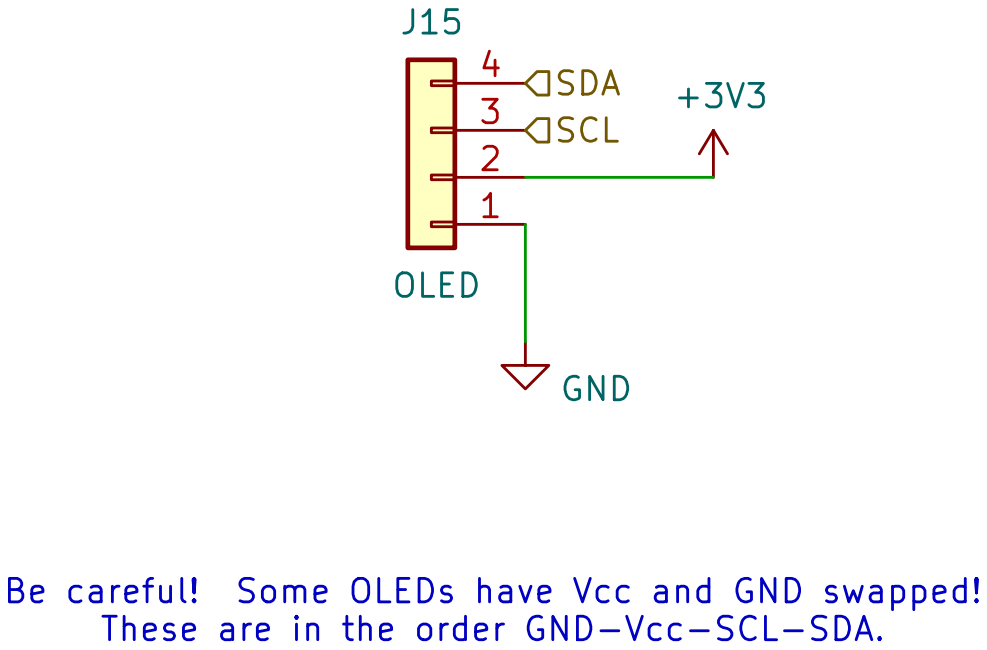
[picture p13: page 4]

SCL SDA Be careful! Some OLEDs have Vcc and GND swapped! These are in the order GND-Vcc-SCL-SDA.

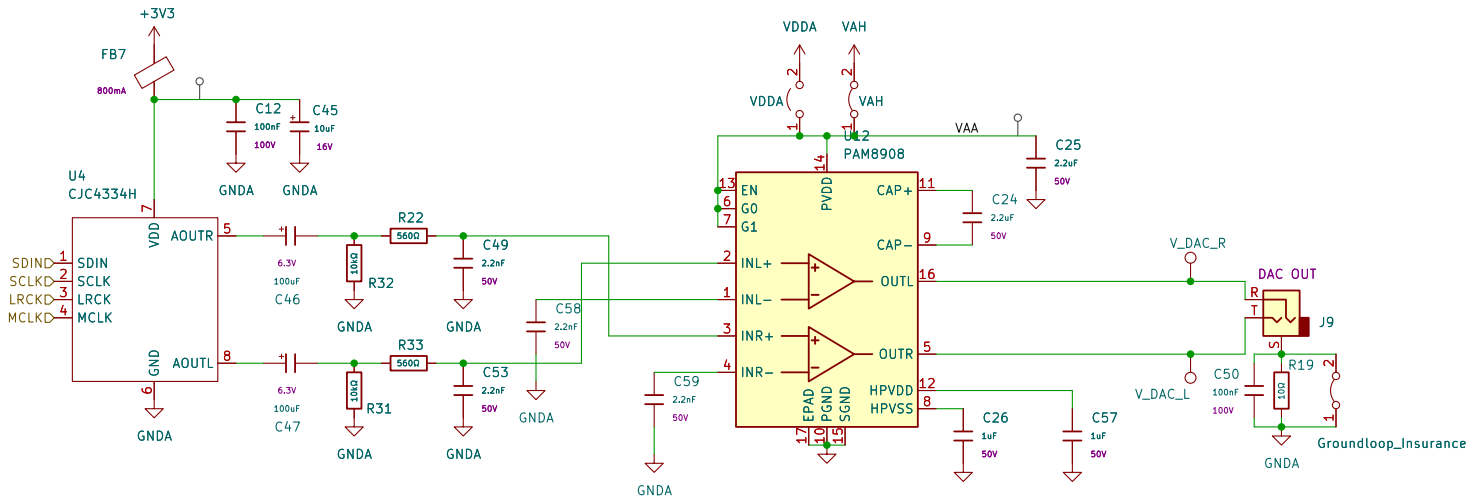
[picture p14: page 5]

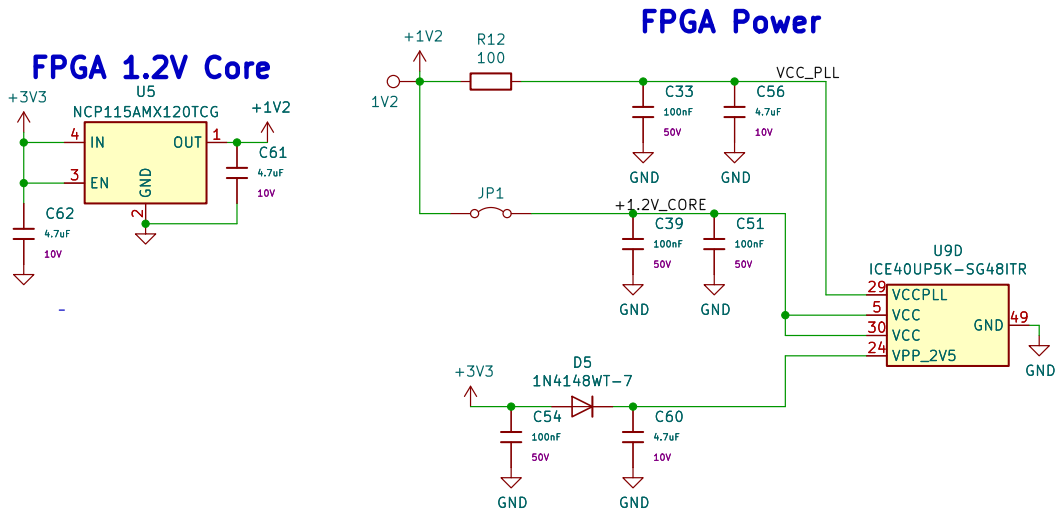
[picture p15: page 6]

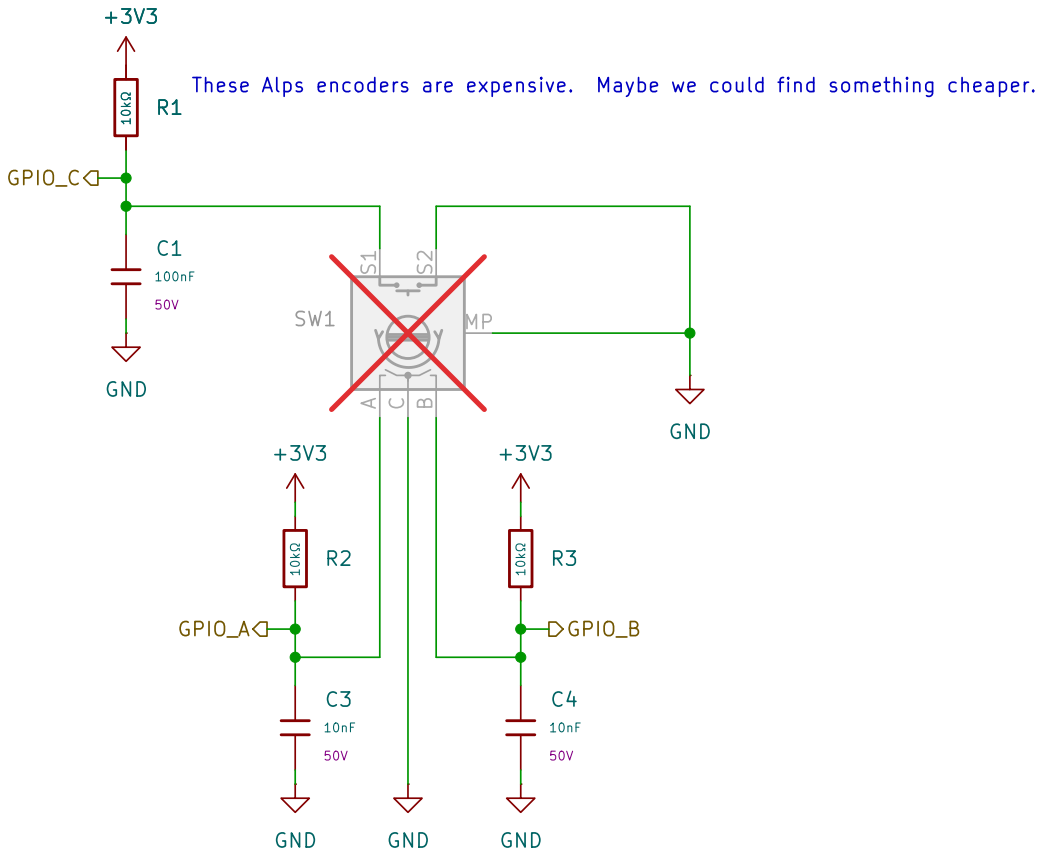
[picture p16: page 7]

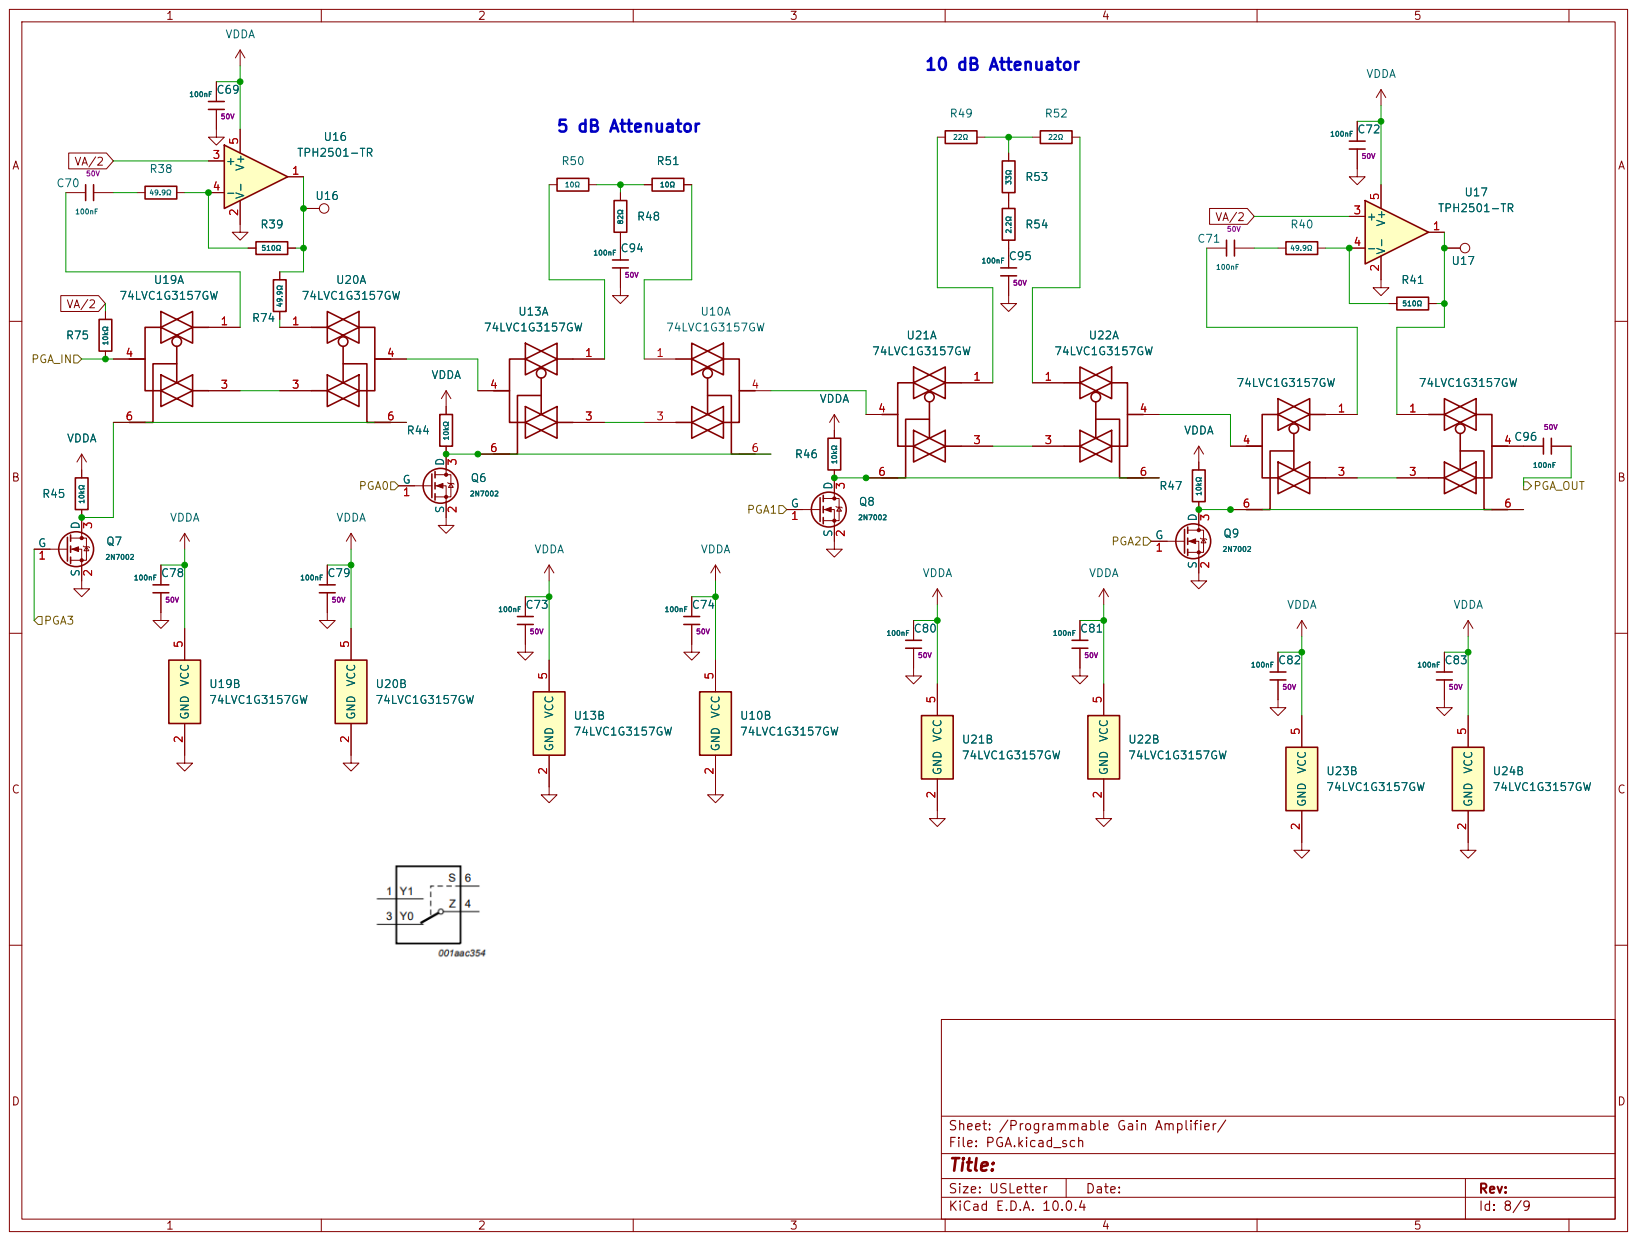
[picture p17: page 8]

Sheet: /Programmable Gain Amplifier/
File: PGA.kicad_sch
Title:

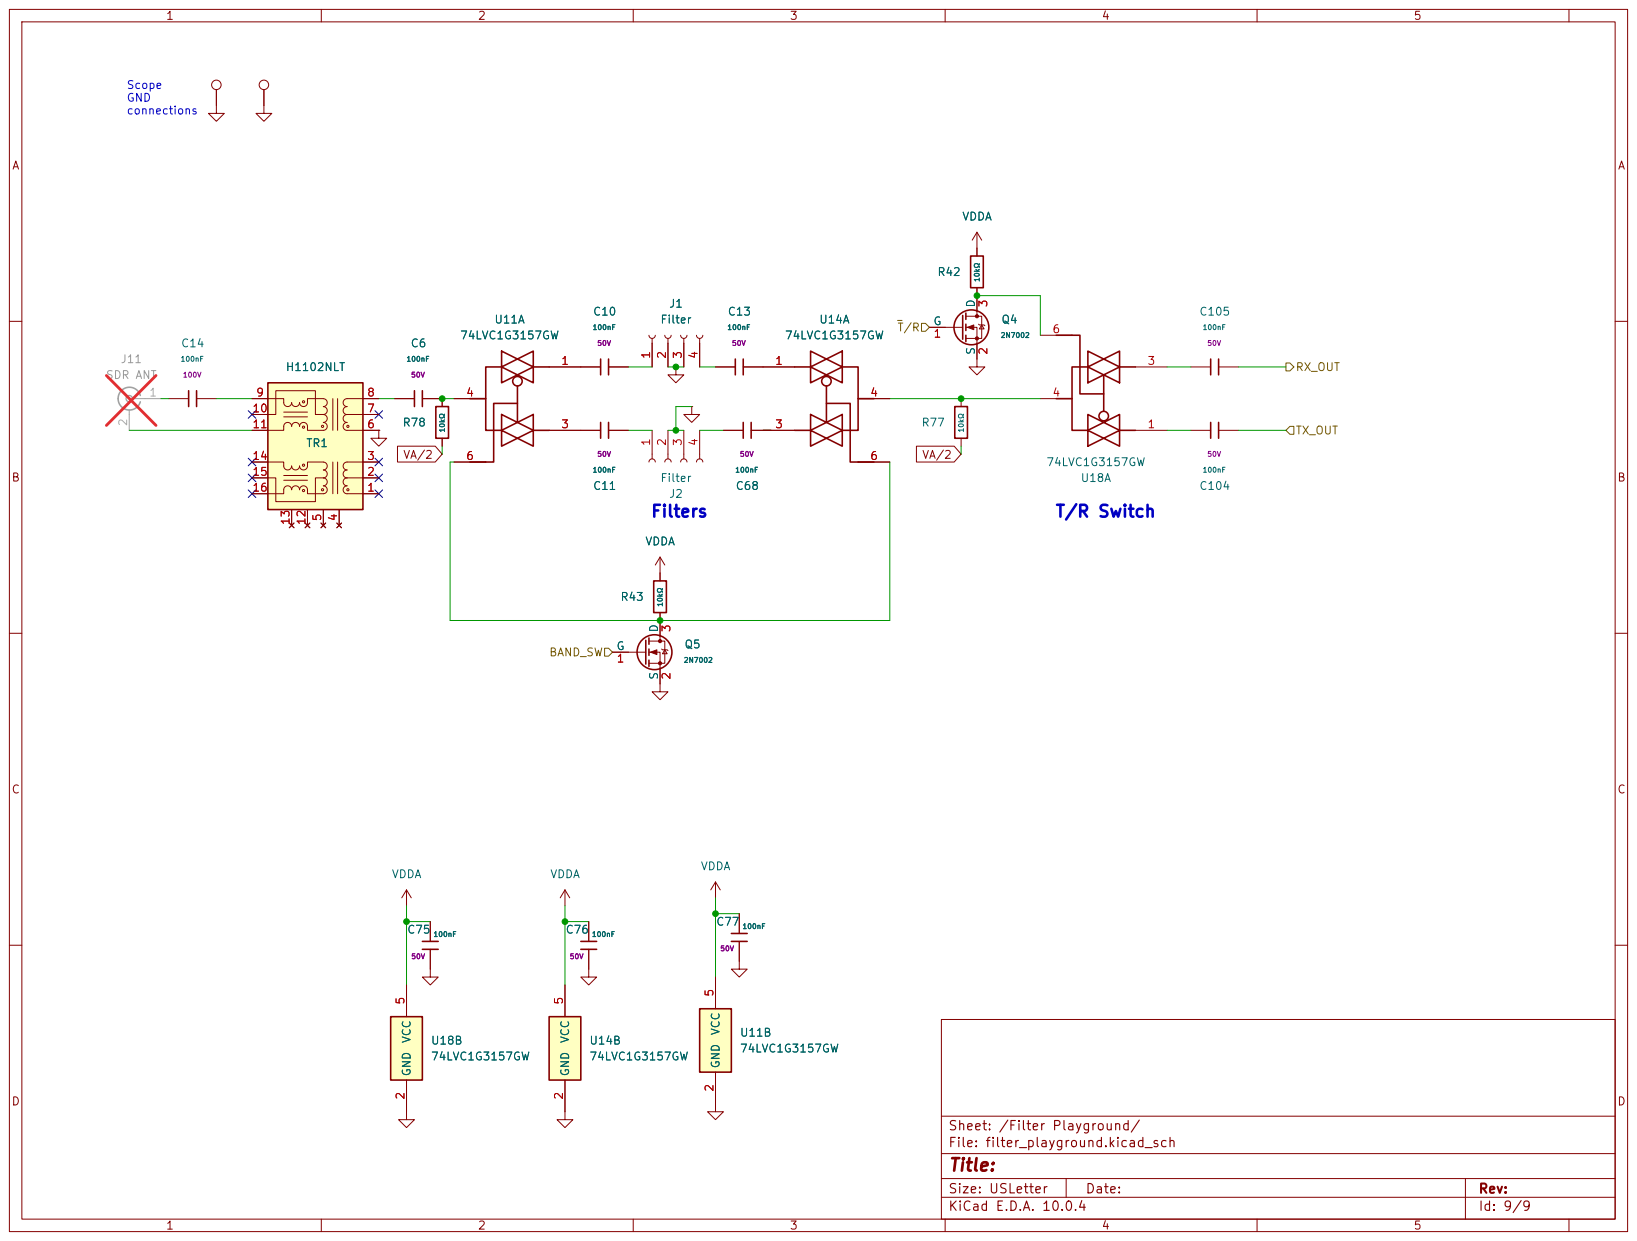
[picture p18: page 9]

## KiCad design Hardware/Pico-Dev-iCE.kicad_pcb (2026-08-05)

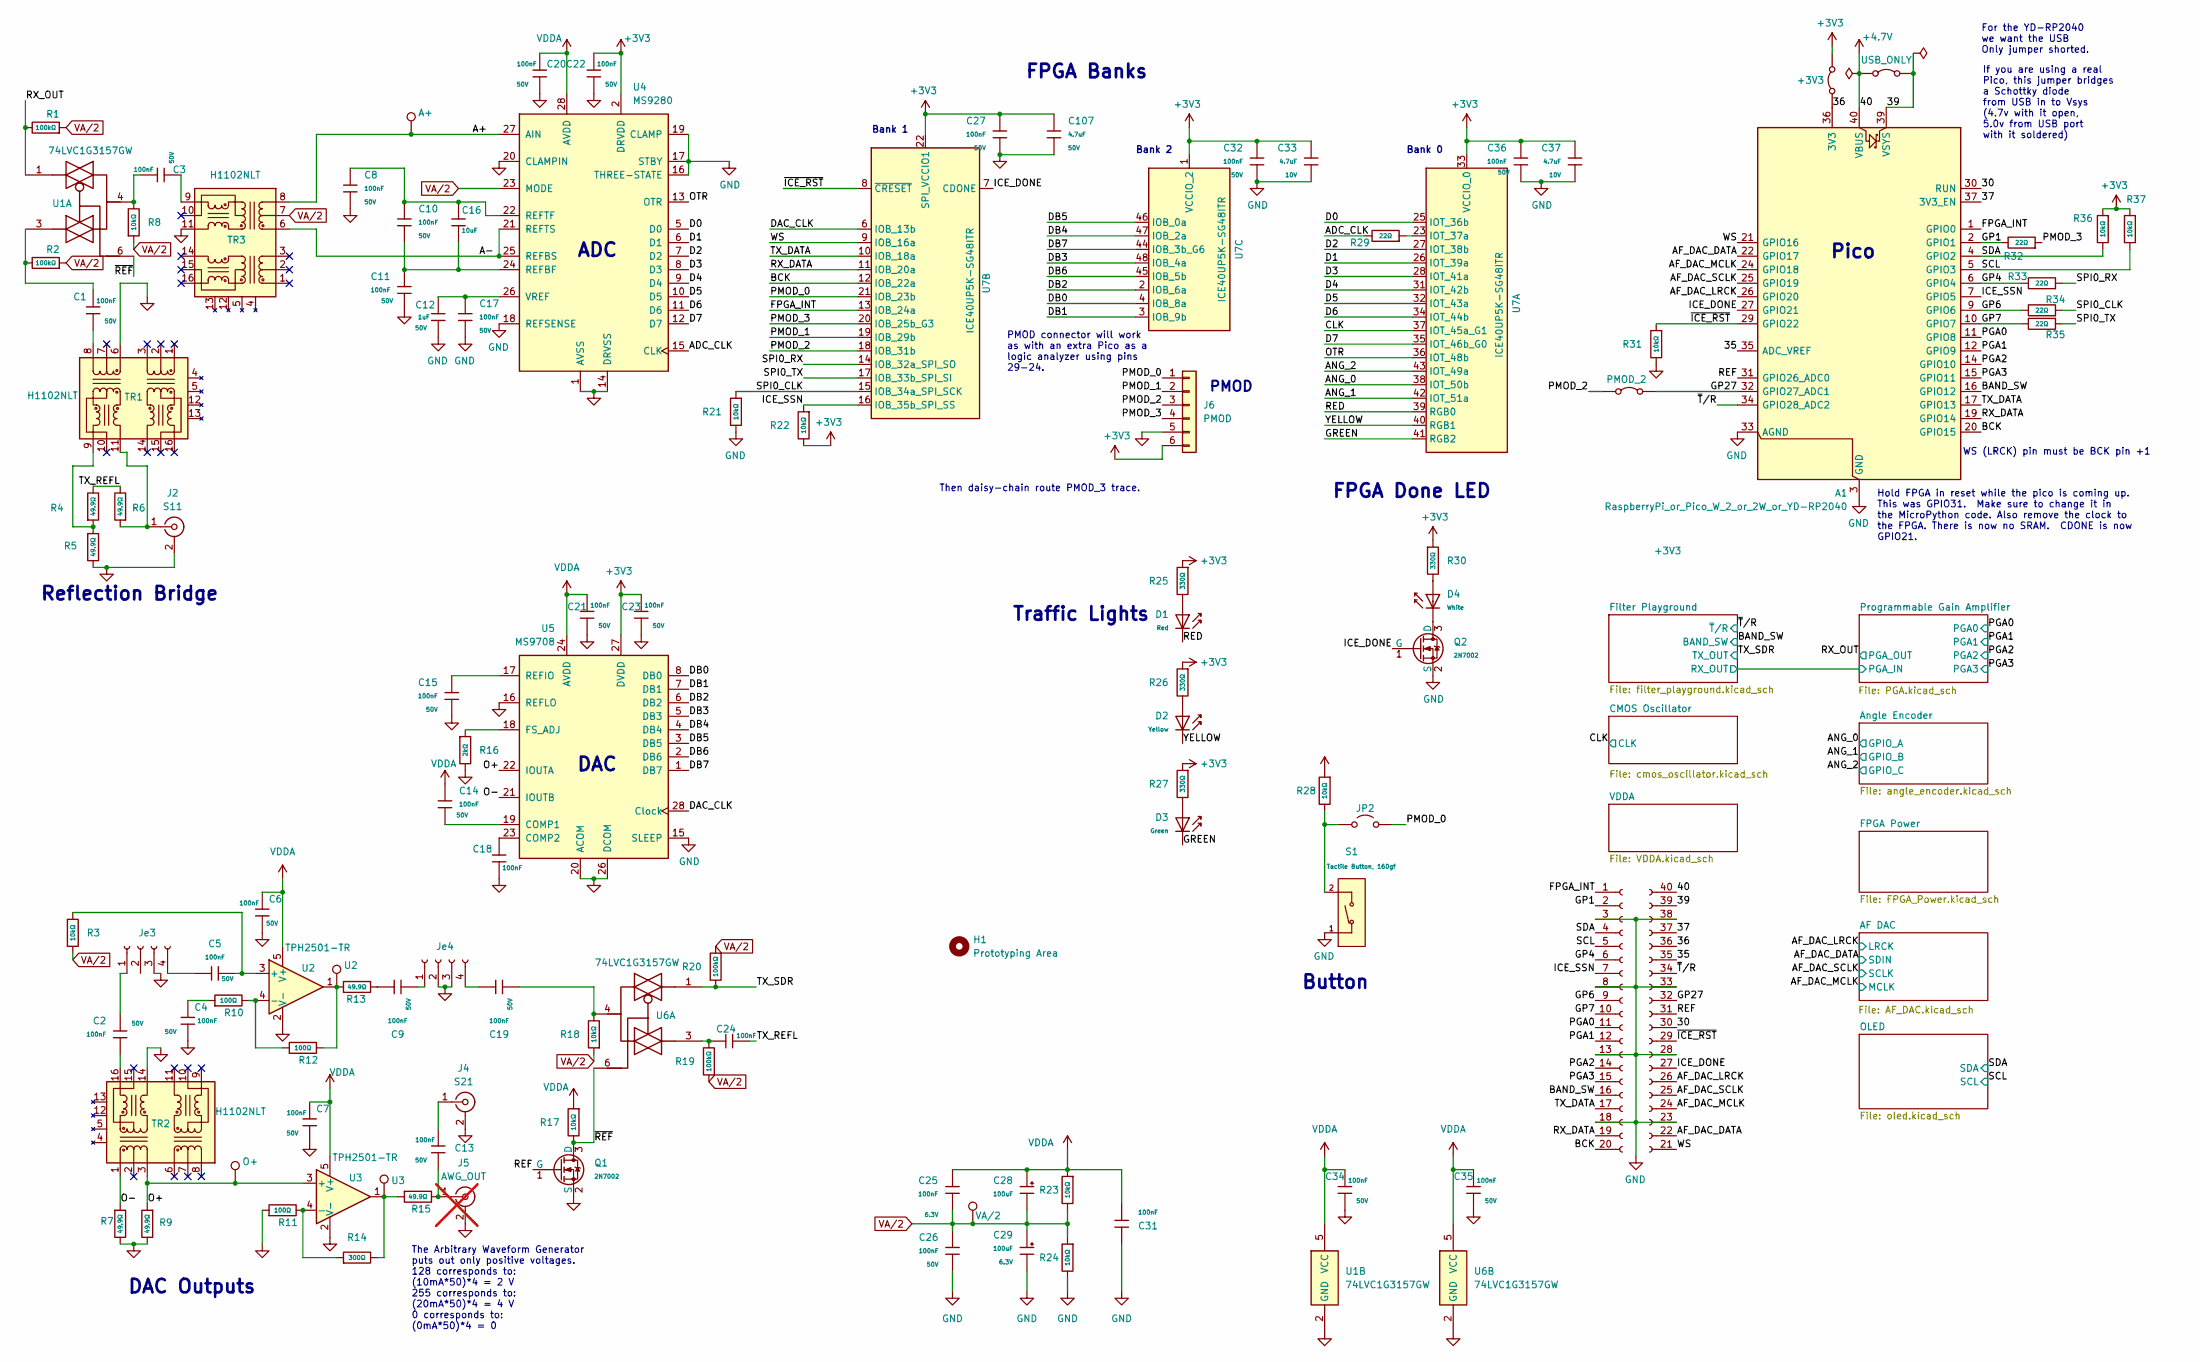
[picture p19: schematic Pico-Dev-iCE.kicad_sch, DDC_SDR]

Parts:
A1: RaspberryPi_or_Pico_W_2_or_2W_or_YD-RP2040; RaspberryPi_Pico_Common_THT
C1, C2, C3, C4, C5, C6, C7, C8, C9, C10, C11, C13, C14, C15, C17, C18, C19, C20, C21, C22, C23, C24, C25, C26, C27, C31, C32, C34, C35, C36: 100nF; C_0402; Voltage Rated 50V; Tolerance ±10%; Part CL05B104KB54PNC; LCSC C307331
C12: 1uF; C_0603; Voltage Rated 50V; Tolerance ±10%; Part CL10A105KB8NNNC; LCSC C15849
C16: 10uF; C_0805; Voltage Rated 50V; Tolerance ±10%; Part GRM21BR61H106KE43L; LCSC C440198
C28, C29: 100uF; C_CASE-B-3528-21(mm); Tolerance ±10%; Rated Voltage 6.3V; Part TAJB107K006RNJ; LCSC C16133
C33, C37: 4.7uF; C_0402; Voltage Rated 10V; Tolerance ±20%; Part CL05A475MP5NRNC; LCSC C23733
C107: 4.7uF; C_1206; Voltage Rated 50V; Tolerance ±10%; Part 1206B475K500NT; LCSC C29823
D1: Red; D_0805; Forward Voltage (VF) 1.6V~2.6V; Part NCD0805R1; LCSC C84256
D2: Yellow; D_0805; Part KT-0805Y; LCSC C2296
D3: Green; D_0805; Part KT-0805G; LCSC C2297
D4: White; D_0805; Part KT-0805W; LCSC C34499
H1: Prototyping Area; Prototype_array
J2: S11; SMA_Samtec_SMA-J-P-H-ST-EM1_EdgeMount; LCSC C52766461
J4: S21; SMA_Samtec_SMA-J-P-H-ST-EM1_EdgeMount; LCSC C52766461
J5: AWG_OUT; Conn_Coaxial_Frohne; not fitted
J6: PMOD; PinSocket_1x06_P2.54mm_Vertical; LCSC C52148815
J11: Conn_01x20_Socket; PinSocket_1x20_P2.54mm_Vertical; LCSC C2905423
J12: Conn_01x20_Socket; PinSocket_1x20_P2.54mm_Vertical-pins21-40; LCSC C2905423
JP2: Jumper_2_Open; SolderJumper-2_P1.3mm_Open_RoundedPad1.0x1.5mm
JP3: PMOD_2; SolderJumper-2_P1.3mm_Bridged2Bar_RoundedPad1.0x1.5mm
JP4: USB_ONLY; SolderJumper-2_P1.3mm_Bridged2Bar_RoundedPad1.0x1.5mm
JP8: +3V3; SolderJumper-2_P1.3mm_Bridged2Bar_RoundedPad1.0x1.5mm
Je3, Je4: Filter; PinHeader_1x04_P2.54mm_Vertical; LCSC C2718488
Q1, Q2: 2N7002; Q_SOT-23; Part 2N7002K; LCSC C22379475
R1, R2, R19, R20: 100kΩ; R_0402; Overload Voltage (Max) 50V; Tolerance ±1%; Part 0402WGF1003TCE; LCSC C25741
R3, R8, R17, R18, R21, R22, R23, R24, R28, R31, R36, R37: 10kΩ; R_0402; Overload Voltage (Max) 50V; Tolerance ±1%; Part 0402WGF1002TCE; LCSC C25744
R4, R5, R6, R7, R9, R13, R15: 49.9Ω; R_0402; Overload Voltage (Max) 50V; Tolerance ±1%; Part 0402WGF499JTCE; LCSC C25120
R10, R11, R12: 100Ω; R_0805; Overload Voltage (Max) 150V; Tolerance ±1%; Part 0805W8F1000T5E; LCSC C17408
R14: 300Ω; R_0805; Overload Voltage (Max) 150V; Tolerance ±1%; Part 0805W8F3000T5E; LCSC C17617
R16: 2kΩ; R_0402; Overload Voltage (Max) 50V; Tolerance ±1%; Part 0402WGF2001TCE; LCSC C4109
R25, R26, R27, R30: 330Ω; R_0402; Overload Voltage (Max) 50V; Tolerance ±1%; Part 0402WGF3300TCE; LCSC C25104
R29, R32, R33, R34, R35: 22Ω; R_0402; Overload Voltage (Max) 50V; Tolerance ±1%; Part 0402WGF220JTCE; LCSC C25092
S1: Tactile Button, 160gf; SW_TS-1088-AR02016; Voltage Rating (Dc) 12V; Part TS-1088-AR02016; LCSC C720477
TP1: U2; TestPoint_THTPad_D2.5mm_Drill1.2mm
TP2: U3; TestPoint_THTPad_D2.5mm_Drill1.2mm
TP3: VA/2; TestPoint_THTPad_D2.5mm_Drill1.2mm
TP14: O+; TestPoint_THTPad_D2.5mm_Drill1.2mm
TP15: A+; TestPoint_THTPad_D2.5mm_Drill1.2mm
TR1, TR2, TR3: H1102NLT; Transformer_Ethernet_Wuerth_749013011A; LCSC C20623173
U1, U6: 74LVC1G3157GW; SOT-363_SC-70-6; LCSC C52140494
U2, U3: TPH2501-TR; SOT-23-5; LCSC C126713
U4: MS9280; SSOP-28_5.3x10.2mm_P0.65mm; LCSC C1509021
U5: MS9708; TSSOP-28-1EP_4.4x9.7mm_P0.65mm_EP3.4x9.7mm_Mask3.1x4.05mm_T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; LCSC C1509022
U7: ICE40UP5K-SG48ITR; QFN-48-1EP_7x7mm_P0.5mm_EP5.6x5.6mm; MPN ICE40UP5K-SG48I; LCSC C2678152

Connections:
+3V3: C22.1, C23.1, C27.1, C32.1, C33.1, C36.1, C37.1, C107.1, J6.6, JP8.2 (B), R22.2, R25.1, R26.1, R27.1, R28.1, R30.1, R36.1, R37.1, U4.2 (DRVDD), U5.27 (DVDD), U7.1 (VCCIO_2), U7.22 (SPI_VCCIO1), U7.33 (VCCIO_0); also elsewhere on the board
+4.7V: A1.40 (VBUS), J12.40 (Pin_1), JP4.1 (A); also elsewhere on the board
/30: A1.30 (RUN), J12.30 (Pin_11)
/35: A1.35 (ADC_VREF), J12.35 (Pin_6)
/36: A1.36 (3V3), J12.36 (Pin_5), JP8.1 (A)
/37: A1.37 (3V3_EN), J12.37 (Pin_4)
/39: A1.39 (VSYS), J12.39 (Pin_2), JP4.2 (B)
/A+: TP15.1 (1_1), TR3.8 (RD-), U4.27 (AIN)
/A-: TR3.6 (RD+), U4.21 (REFTS), U4.25 (REFBS)
/ADC_CLK: R29.2, U4.15 (CLK)
/AF_DAC_DATA: A1.22 (GPIO17), J12.22 (Pin_19); also elsewhere on the board
/AF_DAC_LRCK: A1.26 (GPIO20), J12.26 (Pin_15); also elsewhere on the board
/AF_DAC_MCLK: A1.24 (GPIO18), J12.24 (Pin_17); also elsewhere on the board
/AF_DAC_SCLK: A1.25 (GPIO19), J12.25 (Pin_16); also elsewhere on the board
/ANG_0: U7.38 (IOT_50b); also elsewhere on the board
/ANG_1: U7.42 (IOT_51a); also elsewhere on the board
/ANG_2: U7.43 (IOT_49a); also elsewhere on the board
/BAND_SW: A1.16 (GPIO12), J11.16; also elsewhere on the board
/BCK: A1.20 (GPIO15), J11.20, U7.12 (IOB_22a)
/CLK: U7.37 (IOT_45a_G1); also elsewhere on the board
/D0: U4.5 (D0), U7.25 (IOT_36b)
/D1: U4.6 (D1), U7.26 (IOT_39a)
/D2: U4.7 (D2), U7.27 (IOT_38b)
/D3: U4.8 (D3), U7.28 (IOT_41a)
/D4: U4.9 (D4), U7.31 (IOT_42b)
/D5: U4.10 (D5), U7.32 (IOT_43a)
/D6: U4.11 (D6), U7.34 (IOT_44b)
/D7: U4.12 (D7), U7.35 (IOT_46b_G0)
/DAC_CLK: U5.28 (Clock), U7.6 (IOB_13b)
/DB0: U5.8 (DB0), U7.4 (IOB_8a)
/DB1: U5.7 (DB1), U7.3 (IOB_9b)
/DB2: U5.6 (DB2), U7.2 (IOB_6a)
/DB3: U5.5 (DB3), U7.48 (IOB_4a)
/DB4: U5.4 (DB4), U7.47 (IOB_2a)
/DB5: U5.3 (DB5), U7.46 (IOB_0a)
/DB6: U5.2 (DB6), U7.45 (IOB_5b)
/DB7: U5.1 (DB7), U7.44 (IOB_3b_G6)
/FPGA_INT: A1.1 (GPIO0), J11.1, U7.13 (IOB_24a)
/GP1: A1.2 (GPIO1), J11.2, R32.2
/GP4: A1.6 (GPIO4), J11.6, R33.2
/GP6: A1.9 (GPIO6), J11.9, R34.2
/GP7: A1.10 (GPIO7), J11.10, R35.2
/GP27: A1.32 (GPIO27_ADC1), J12.32 (Pin_9), JP3.2 (B)
/GREEN: D3.1, U7.41 (RGB2)
/ICE_DONE: A1.27 (GPIO21), J12.27 (Pin_14), Q2.1 (G), U7.7 (CDONE)
/ICE_SSN: A1.7 (GPIO5), J11.7, R22.1, U7.16 (IOB_35b_SPI_SS)
/O+: R9.1, TP14.1 (1_1), TR2.3 (TD-), U3.3 (+), U5.22 (IOUTA)
/O-: R7.1, TR2.1 (TD+), U5.21 (IOUTB)
/OTR: U4.13 (OTR), U7.36 (IOT_48b)
/PGA0: A1.11 (GPIO8), J11.11; also elsewhere on the board
/PGA1: A1.12 (GPIO9), J11.12; also elsewhere on the board
/PGA2: A1.14 (GPIO10), J11.14; also elsewhere on the board
/PGA3: A1.15 (GPIO11), J11.15; also elsewhere on the board
/PMOD_0: J6.1, JP2.1 (A), U7.21 (IOB_23b)
/PMOD_1: J6.2, U7.19 (IOB_29b)
/PMOD_2: J6.3, JP3.1 (A), U7.18 (IOB_31b)
/PMOD_3: J6.4, R32.1, U7.20 (IOB_25b_G3)
/RED: D1.1, U7.39 (RGB0)
/REF: A1.31 (GPIO26_ADC0), J12.31 (Pin_10), Q1.1 (G)
/RX_DATA: A1.19 (GPIO14), J11.19, U7.11 (IOB_20a)
/RX_OUT: R1.2, U1.1; also elsewhere on the board
/SCL: A1.5 (GPIO3), J11.5, R37.2; also elsewhere on the board
/SDA: A1.4 (GPIO2), J11.4, R36.2; also elsewhere on the board
/SPI0_CLK: R21.1, R34.1, U7.15 (IOB_34a_SPI_SCK)
/SPI0_RX: R33.1, U7.14 (IOB_32a_SPI_SO)
/SPI0_TX: R35.1, U7.17 (IOB_33b_SPI_SI)
/TX_DATA: A1.17 (GPIO13), J11.17, U7.10 (IOB_18a)
/TX_REFL: C24.1, R4.2, R6.2
/TX_SDR: R20.2, U6.1; also elsewhere on the board
/WS: A1.21 (GPIO16), J12.21 (Pin_20), U7.9 (IOB_16a)
/YELLOW: D2.1, U7.40 (RGB1)
/~ICE_RST: A1.29 (GPIO22), J12.29 (Pin_12), R31.1, U7.8 (~CRESET)
/~REF: Q1.3 (D), R17.2, U1.6, U6.6
/~T/R: A1.34 (GPIO28_ADC2), J12.34 (Pin_7); also elsewhere on the board
GND: A1.3 (GND), A1.8 (GND), A1.13 (GND), A1.18 (GND), A1.23 (GND), A1.28 (GND), A1.33 (AGND), A1.38 (GND), C4.2, C6.2, C7.2, C8.2, C11.2, C12.2, C15.2, C17.2, C18.2, C20.2, C21.2, C22.2, C23.2, C26.1, C27.2, C29.2, C31.1, C32.2, C33.2, C34.2, C35.2, C36.2, C37.2, C107.2, J2.2 (Ext), J4.2 (Ext), J5.2 (Ext), J6.5, J11.3, J11.8, J11.13, J11.18, J12.23 (Pin_18), J12.28 (Pin_13), J12.33 (Pin_8), J12.38 (Pin_3), Je3.3, Je4.2, Je4.3, Q1.2 (S), Q2.2 (S), R5.2, R7.2, R9.2, R11.1, R16.2, R21.2, R24.2, R31.2, S1.1 (A), TR1.6 (RD+), TR2.14 (TX-), TR3.11 (RX+), U1.2 (GND), U2.2 (V-), U3.2 (V-), U4.1 (AVSS), U4.14 (DRVSS), U4.16 (THREE-STATE), U4.17 (STBY), U4.18 (REFSENSE), U4.19 (CLAMP), U4.20 (CLAMPIN), U5.15 (SLEEP), U5.16 (REFLO), U5.20 (ACOM), U5.26 (DCOM), U6.2 (GND); also elsewhere on the board
unnamed: C1.1, R2.2, U1.3
unnamed: C3.1, R8.2, U1.4
unnamed: C4.1, R10.1
unnamed: C9.1, R13.2
unnamed: C19.2, R18.2, U6.4
unnamed: C24.2, R19.2, U6.3
unnamed: D1.2, R25.2
unnamed: D2.2, R26.2
unnamed: D3.2, R27.2
unnamed: D4.2, R30.2
unnamed: J2.1 (In), R6.1, TR1.11 (RX+)
unnamed: C13.1, J4.1 (In)
unnamed: C13.2, J5.1 (In), R15.2
unnamed: JP2.2 (B), R28.2, S1.2 (B)
unnamed: C2.2, Je3.1
unnamed: C5.1, Je3.4
unnamed: C9.2, Je4.1
unnamed: C19.1, Je4.4
unnamed: D4.1, Q2.3 (D)
unnamed: R12.2, R13.1, TP1.1 (1_1), U2.1
unnamed: R14.2, R15.1, TP2.1 (1_1), U3.1
unnamed: C1.2, TR1.8 (RD-)
unnamed: R4.1, R5.1, TR1.9 (RX-)
unnamed: C2.1, TR2.16 (TX+)
unnamed: C3.2, TR3.9 (RX-)
unnamed: C5.2, R3.2, U2.3 (+)
unnamed: R10.2, R12.1, U2.4 (-)
unnamed: R11.2, R14.1, U3.4 (-)
unnamed: C10.2, C11.1, C16.2, U4.24 (REFBF)
unnamed: C8.1, C10.1, C16.1, U4.22 (REFTF)
unnamed: C12.1, C17.1, U4.26 (VREF)
unnamed: C14.2, U5.19 (COMP1)
unnamed: C18.1, U5.23 (COMP2)
unnamed: R16.1, U5.18 (FS_ADJ)
unnamed: C15.1, U5.17 (REFIO)
unnamed: R29.1, U7.23 (IOT_37a)
VA/2: C25.1, C26.2, C28.2, C29.1, R1.1, R2.1, R3.1, R8.1, R18.1, R19.1, R20.1, R23.2, R24.1, TP3.1 (1_1), TR3.7 (C_RD), U4.23 (MODE); also elsewhere on the board
VDDA: C6.1, C7.1, C14.1, C20.1, C21.1, C25.2, C28.1, C31.2, C34.1, C35.1, R17.1, R23.1, U1.5 (VCC), U2.5 (V+), U3.5 (V+), U4.28 (AVDD), U5.24 (AVDD), U6.5 (VCC); also elsewhere on the board

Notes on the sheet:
FPGA Done LED
Pico
Traffic Lights
Then daisy-chain route PMOD_3 trace.
Bank 1
Bank 0
Hold FPGA in reset while the pico is coming up. This was GPIO31. Make sure to change it in the MicroPython code. Also remove the clock to the FPGA. There is now no SRAM. CDONE is now GPIO21.
WS (LRCK) pin must be BCK pin +1
PMOD
FPGA Banks
If you are using a real Pico, this jumper bridges a Schottky diode from USB in to Vsys (4.7v with it open, 5.0v from USB port with it soldered)
DAC Outputs
Bank 2
The Arbitrary Waveform Generator puts out only positive voltages. 128 corresponds to: (10mA*50)*4 = 2 V 255 corresponds to: (20mA*50)*4 = 4 V 0 corresponds to: (0mA*50)*4 = 0
For the YD-RP2040 we want the USB Only jumper shorted.
DAC
Reflection Bridge
Button
PMOD connector will work as with an extra Pico as a logic analyzer using pins 29-24.
ADC

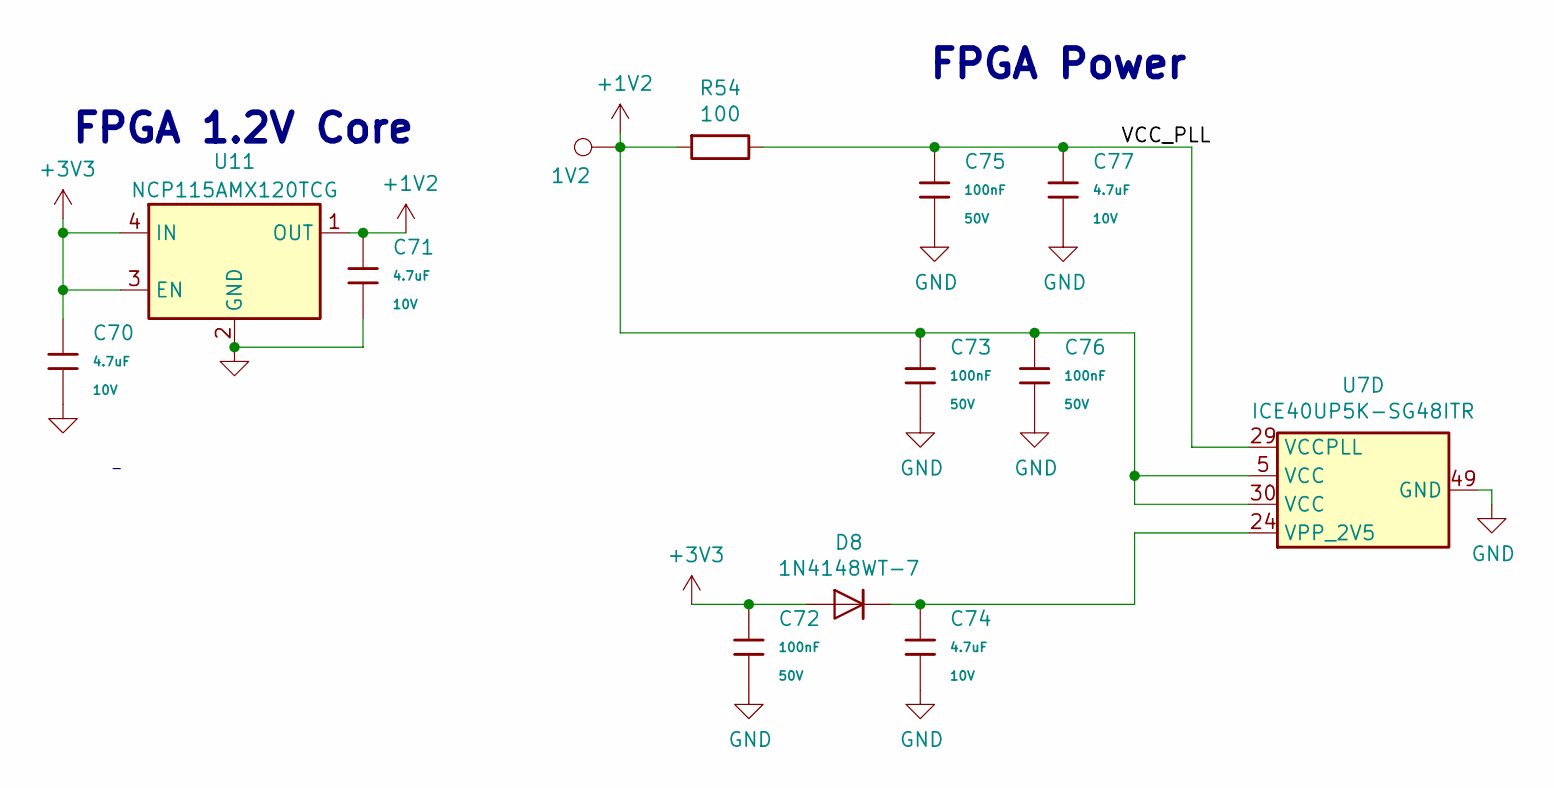
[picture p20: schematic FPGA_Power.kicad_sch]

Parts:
C70, C71, C74, C77: 4.7uF; C_0402; Voltage Rated 10V; Tolerance ±20%; Part CL05A475MP5NRNC; LCSC C23733
C72, C73, C75, C76: 100nF; C_0402; Voltage Rated 50V; Tolerance ±10%; Part CL05B104KB54PNC; LCSC C307331
D8: 1N4148WT-7; D_SOD-523; MPN 1N4148WT-7; LCSC C27748
R54: 100; R_0402_1005Metric; MPN RC0402FR-07100RL; LCSC C25076
TP9: 1V2; TestPoint_THTPad_D2.5mm_Drill1.2mm
U7: ICE40UP5K-SG48ITR; QFN-48-1EP_7x7mm_P0.5mm_EP5.6x5.6mm; MPN ICE40UP5K-SG48I; LCSC C2678152
U11: NCP115AMX120TCG; OnSemi_XDFN4-1EP_1.0x1.0mm_EP0.52x0.52mm; MPN NCP115AMX120TCG; LCSC C603500

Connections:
+1V2: C71.1, C73.1, C76.1, R54.2, TP9.1 (1_1), U7.5 (VCC), U7.30 (VCC), U11.1 (OUT)
+3V3: C70.1, C72.1, D8.2 (A), U11.3 (EN), U11.4 (IN); also elsewhere on the board
/FPGA Power/VCC_PLL: C75.1, C77.1, R54.1, U7.29 (VCCPLL)
GND: C70.2, C71.2, C72.2, C73.2, C74.2, C75.2, C76.2, C77.2, U7.49 (GND), U11.2 (GND), U11.5 (GND); also elsewhere on the board
unnamed: C74.1, D8.1 (K), U7.24 (VPP_2V5)

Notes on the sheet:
FPGA Power
FPGA 1.2V Core

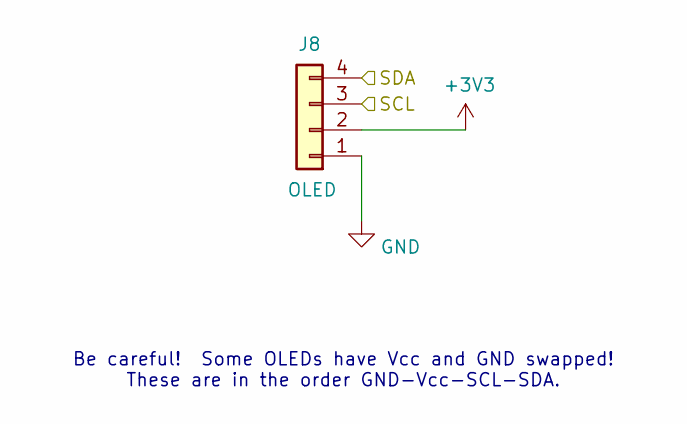
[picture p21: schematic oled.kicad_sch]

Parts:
J8: OLED; PinSocket_1x04_P2.54mm_Vertical; LCSC C2718488

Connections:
+3V3: J8.2; also elsewhere on the board
/SCL: J8.3; also elsewhere on the board
/SDA: J8.4; also elsewhere on the board
GND: J8.1; also elsewhere on the board

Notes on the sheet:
Be careful! Some OLEDs have Vcc and GND swapped! These are in the order GND-Vcc-SCL-SDA.

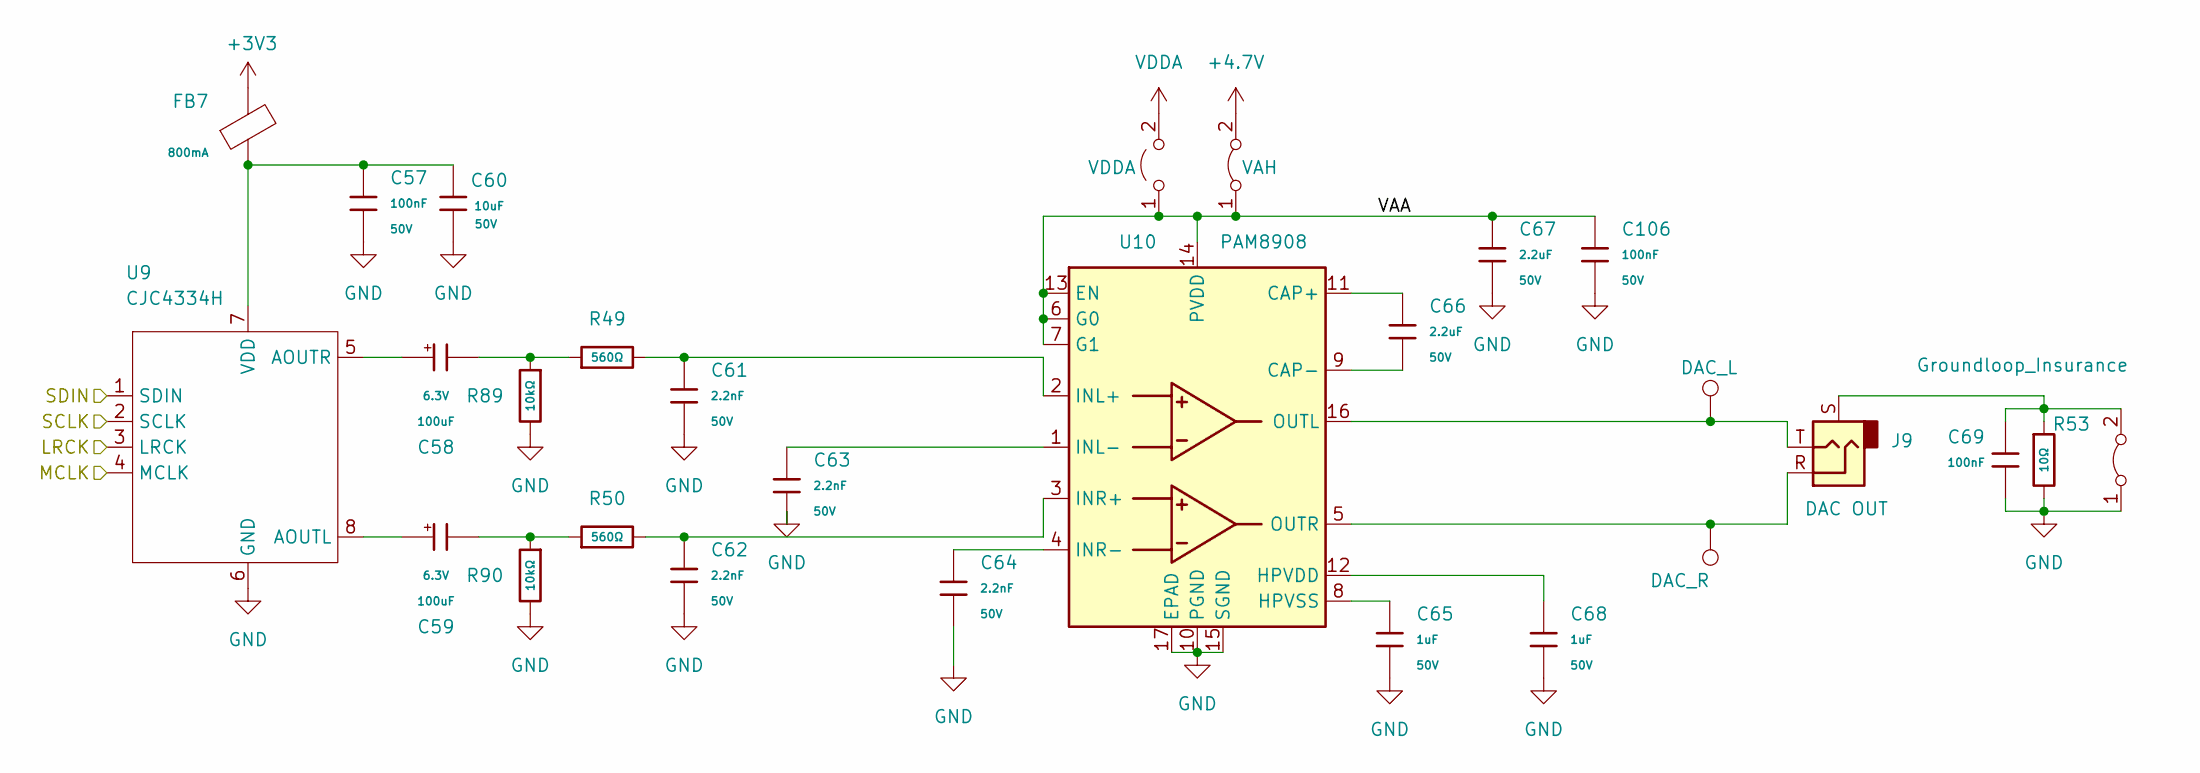
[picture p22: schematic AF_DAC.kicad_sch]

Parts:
C57, C69, C106: 100nF; C_0402; Voltage Rated 50V; Tolerance ±10%; Part CL05B104KB54PNC; LCSC C307331
C58, C59: 100uF; C_CASE-B-3528-21(mm); Tolerance ±10%; Rated Voltage 6.3V; Part TAJB107K006RNJ; LCSC C16133
C60: 10uF; C_0805; Tolerance ±10%; Rated Voltage 16V; Part GRM21BR61H106KE43L; LCSC C440198
C61, C62, C63, C64: 2.2nF; C_0805; Voltage Rated 50V; Tolerance ±5%; Part CL21C222JBFNNNE; LCSC C28260
C65, C68: 1uF; C_0603; Voltage Rated 50V; Tolerance ±10%; Part CL10A105KB8NNNC; LCSC C15849
C66, C67: 2.2uF; C_0805; Voltage Rated 50V; Tolerance ±10%; Part CL21A225KBQNNNE; LCSC C377773
FB7: FB_0805; Current Rating 800mA; Tolerance ±25%; Part GZ2012D101TF; LCSC C1015
J9: 3.5mm_Jack; Jack_3.5mm_CUI_SJ-3523-SMT_Horizontal; LCSC C18594
JP6: VDDA; SolderJumper-2_P1.3mm_Open_RoundedPad1.0x1.5mm
R49, R50: 560Ω; R_0603; Overload Voltage (Max) 75V; Tolerance ±1%; Part 0603WAF5600T5E; LCSC C23204
R53: 10Ω; R_0603; Overload Voltage (Max) 75V; Tolerance ±1%; Part 0603WAF100JT5E; LCSC C22859
R89, R90: 10kΩ; R_0402; Overload Voltage (Max) 50V; Tolerance ±1%; Part 0402WGF1002TCE; LCSC C25744
TP7: DAC_L; TestPoint_THTPad_D2.5mm_Drill1.2mm
TP8: DAC_R; TestPoint_THTPad_D2.5mm_Drill1.2mm
U9: CJC4334H; SOIC-8_3.9x4.9mm_P1.27mm; LCSC C41417670
U10: PAM8908; QFN-16-1EP_3x3mm_P0.5mm_EP1.7x1.7mm; LCSC C33233
e3: VAH; SolderJumper-2_P1.3mm_Bridged_RoundedPad1.0x1.5mm
e4: Groundloop_Insurance; SolderJumper-2_P1.3mm_Bridged_RoundedPad1.0x1.5mm

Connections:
+3V3: FB7.2; also elsewhere on the board
+4.7V: e3.2 (B); also elsewhere on the board
/AF DAC/VAA: C67.1, C106.1, JP6.1 (A), U10.6 (G0), U10.7 (G1), U10.13 (EN), U10.14 (PVDD), e3.1 (A)
/AF_DAC_DATA: U9.1 (SDIN); also elsewhere on the board
/AF_DAC_LRCK: U9.3 (LRCK); also elsewhere on the board
/AF_DAC_MCLK: U9.4 (MCLK); also elsewhere on the board
/AF_DAC_SCLK: U9.2 (SCLK); also elsewhere on the board
GND: C57.2, C60.2, C61.2, C62.2, C63.2, C64.2, C65.2, C67.2, C68.2, C69.1, C106.2, R53.2, R89.2, R90.2, U9.6 (GND), U10.10 (PGND), U10.15 (SGND), U10.17 (EPAD), e4.1 (A); also elsewhere on the board
unnamed: C58.2, R49.1, R89.1
unnamed: C59.2, R50.1, R90.1
unnamed: C59.1, U9.8 (AOUTL)
unnamed: C58.1, U9.5 (AOUTR)
unnamed: C57.1, C60.1, FB7.1, U9.7 (VDD)
unnamed: C66.1, U10.11 (CAP+)
unnamed: C66.2, U10.9 (CAP-)
unnamed: C68.1, U10.12 (HPVDD)
unnamed: C65.1, U10.8 (HPVSS)
unnamed: C61.1, R49.2, U10.2 (INL+)
unnamed: C63.1, U10.1 (INL-)
unnamed: C62.1, R50.2, U10.3 (INR+)
unnamed: C64.1, U10.4 (INR-)
unnamed: J9.T, TP7.1 (1_1), U10.16 (OUTL)
unnamed: J9.R, TP8.1 (1_1), U10.5 (OUTR)
unnamed: C69.2, J9.S, R53.1, e4.2 (B)
VDDA: JP6.2 (B); also elsewhere on the board

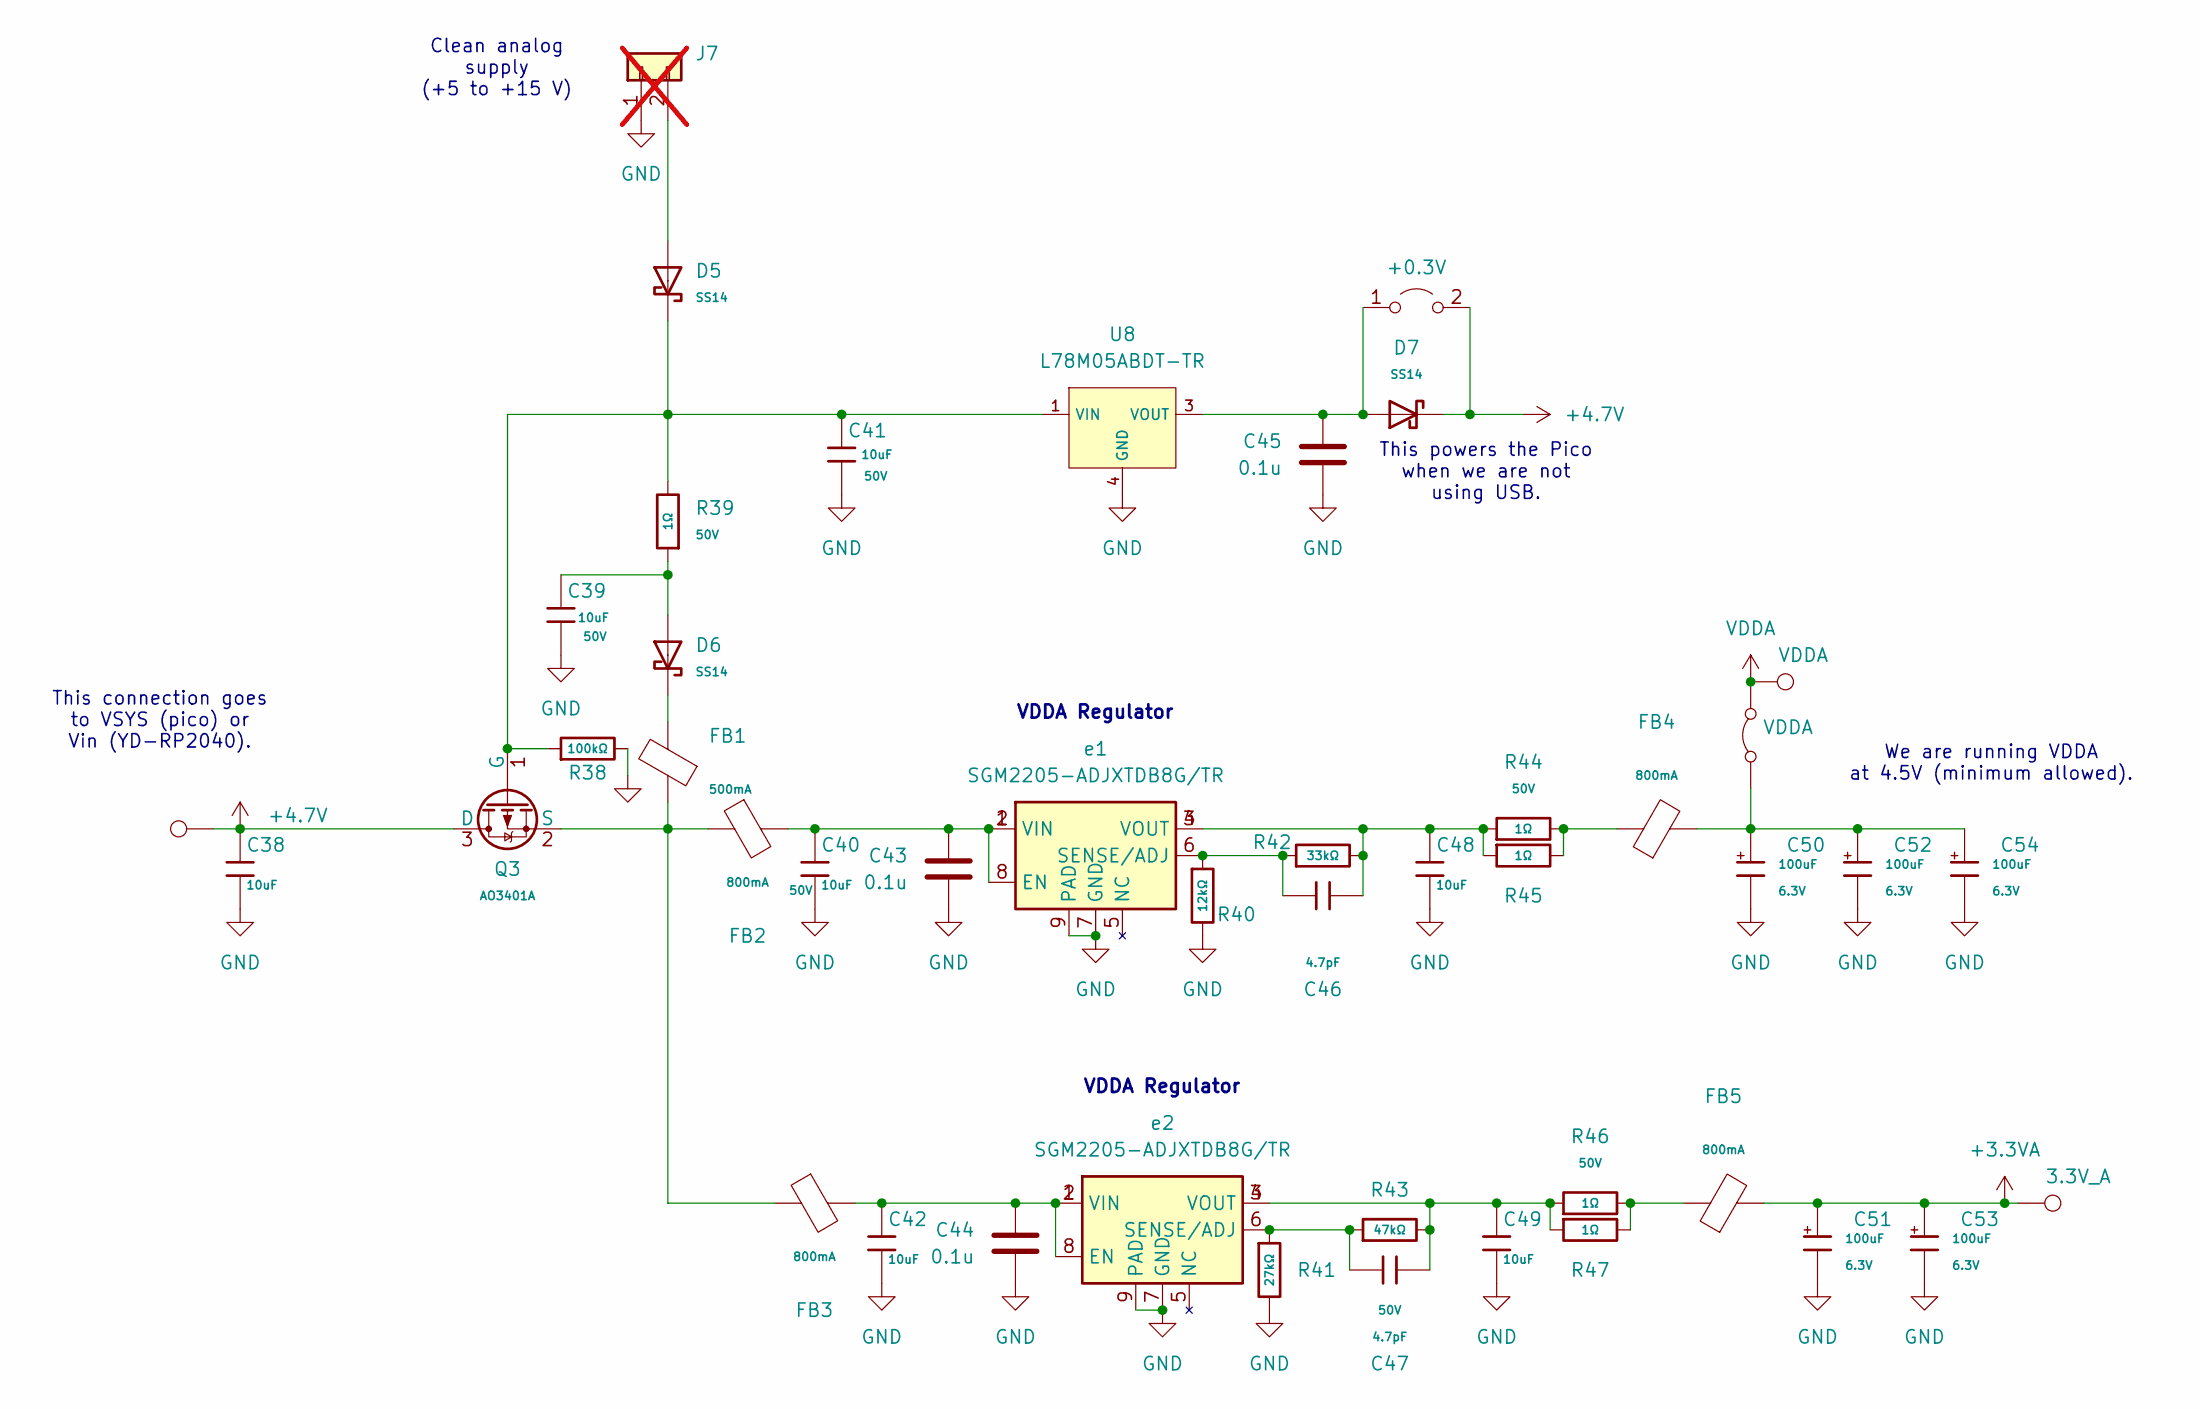
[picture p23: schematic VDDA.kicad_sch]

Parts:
C38, C39, C40, C41, C42, C48, C49: 10uF; C_0805; Voltage Rated 50V; Tolerance ±10%; Part GRM21BR61H106KE43L; LCSC C440198
C43, C44, C45: 0.1u; C_0805_2012Metric; LCSC C49678
C46, C47: 4.7pF; C_0603; Voltage Rated 50V; Part 0603CG4R7C500NT; LCSC C1669
C50, C51, C52, C53, C54: 100uF; C_CASE-B-3528-21(mm); Tolerance ±10%; Rated Voltage 6.3V; Part TAJB107K006RNJ; LCSC C16133
D5, D6, D7: SS14; D_SMA; Forward Voltage (Vf@If) 550mV@1A; Reverse Voltage (Vr) 40V; Part SS14; LCSC C2480
FB1: FB_0805; Current Rating 500mA; Tolerance ±25%; Part GZ2012D601TF; LCSC C1017
FB2, FB3, FB4, FB5: FB_0805; Current Rating 800mA; Tolerance ±25%; Part GZ2012D101TF; LCSC C1015
J7: Conn_01x02; PinHeader_1x02_P2.54mm_Vertical; not fitted
JP5: +0.3V; SolderJumper-2_P1.3mm_Open_RoundedPad1.0x1.5mm
JP7: VDDA; SolderJumper-2_P1.3mm_Bridged2Bar_RoundedPad1.0x1.5mm
Q3: AO3401A; Q_SOT-23; Part AO3401A; LCSC C15127
R38: 100kΩ; R_0805; Overload Voltage (Max) 150V; Tolerance ±1%; Part 0805W8F1003T5E; LCSC C149504
R39, R44, R45, R46, R47: 1Ω; R_0603; Overload Voltage (Max) 75V; Tolerance ±1%; Part 0603WAF100KT5E; LCSC C22936
R40: 12kΩ; R_0805; Overload Voltage (Max) 150V; Tolerance ±1%; Part 0805W8F1202T5E; LCSC C17444
R41: 27kΩ; R_0805; Overload Voltage (Max) 150V; Tolerance ±1%; Part 0805W8F2702T5E; LCSC C17593
R42: 33kΩ; R_0805; Overload Voltage (Max) 150V; Tolerance ±1%; Part 0805W8F3302T5E; LCSC C17633
R43: 47kΩ; R_0805; Overload Voltage (Max) 150V; Tolerance ±1%; Part 0805W8F4702T5E; LCSC C17713
TP4: +5; TestPoint_THTPad_D2.5mm_Drill1.2mm
TP5: VDDA; TestPoint_THTPad_D2.5mm_Drill1.2mm
TP6: 3.3V_A; TestPoint_THTPad_D2.5mm_Drill1.2mm
U8: L78M05ABDT-TR; TO-252-2_L6.5-W6.1-P4.58-LS10.0-TL; Output Voltage 5V; Part L78M05ABDT-TR; LCSC C58069
e1, e2: SGM2205-ADJXTDB8G/TR; DFN-8-1EP_3x3mm_P0.65mm_EP1.55x2.4mm; LCSC C5152847

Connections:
+3.3VA: C51.1, C53.1, FB5.2, TP6.1 (1_1); also elsewhere on the board
+4.7V: C38.1, D7.1, JP5.2 (B), Q3.3 (D), TP4.1 (1_1); also elsewhere on the board
GND: C38.2, C39.2, C40.2, C41.2, C42.2, C43.2, C44.2, C45.2, C48.2, C49.2, C50.2, C51.2, C52.2, C53.2, C54.2, J7.1, R38.2, R40.2, R41.2, U8.4 (GND), e1.7 (GND), e1.9 (PAD), e2.7 (GND), e2.9 (PAD); also elsewhere on the board
unnamed: C39.1, D6.2, R39.1
unnamed: C46.1, C48.1, R42.2, R44.1, R45.1, e1.3 (VOUT), e1.4 (VOUT)
unnamed: C47.1, C49.1, R43.2, R46.1, R47.1, e2.3 (VOUT), e2.4 (VOUT)
unnamed: D6.1, FB1.2
unnamed: FB4.1, R44.2, R45.2
unnamed: FB5.1, R46.2, R47.2
unnamed: D5.2, J7.2
unnamed: C45.1, D7.2, JP5.1 (A), U8.3 (VOUT)
unnamed: C50.1, C52.1, C54.1, FB4.2, JP7.1 (A)
unnamed: C41.1, D5.1, Q3.1 (G), R38.1, R39.2, U8.1 (VIN)
unnamed: FB1.1, FB2.1, FB3.1, Q3.2 (S)
unnamed: C40.1, C43.1, FB2.2, e1.1 (VIN), e1.2 (VIN), e1.8 (EN)
unnamed: C46.2, R40.1, R42.1, e1.6 (SENSE/ADJ)
unnamed: C42.1, C44.1, FB3.2, e2.1 (VIN), e2.2 (VIN), e2.8 (EN)
unnamed: C47.2, R41.1, R43.1, e2.6 (SENSE/ADJ)
VDDA: JP7.2 (B), TP5.1 (1_1); also elsewhere on the board

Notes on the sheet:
This connection goes to VSYS (pico) or Vin (YD-RP2040).
VDDA Regulator
We are running VDDA at 4.5V (minimum allowed).
Clean analog supply (+5 to +15 V)
This powers the Pico when we are not using USB.

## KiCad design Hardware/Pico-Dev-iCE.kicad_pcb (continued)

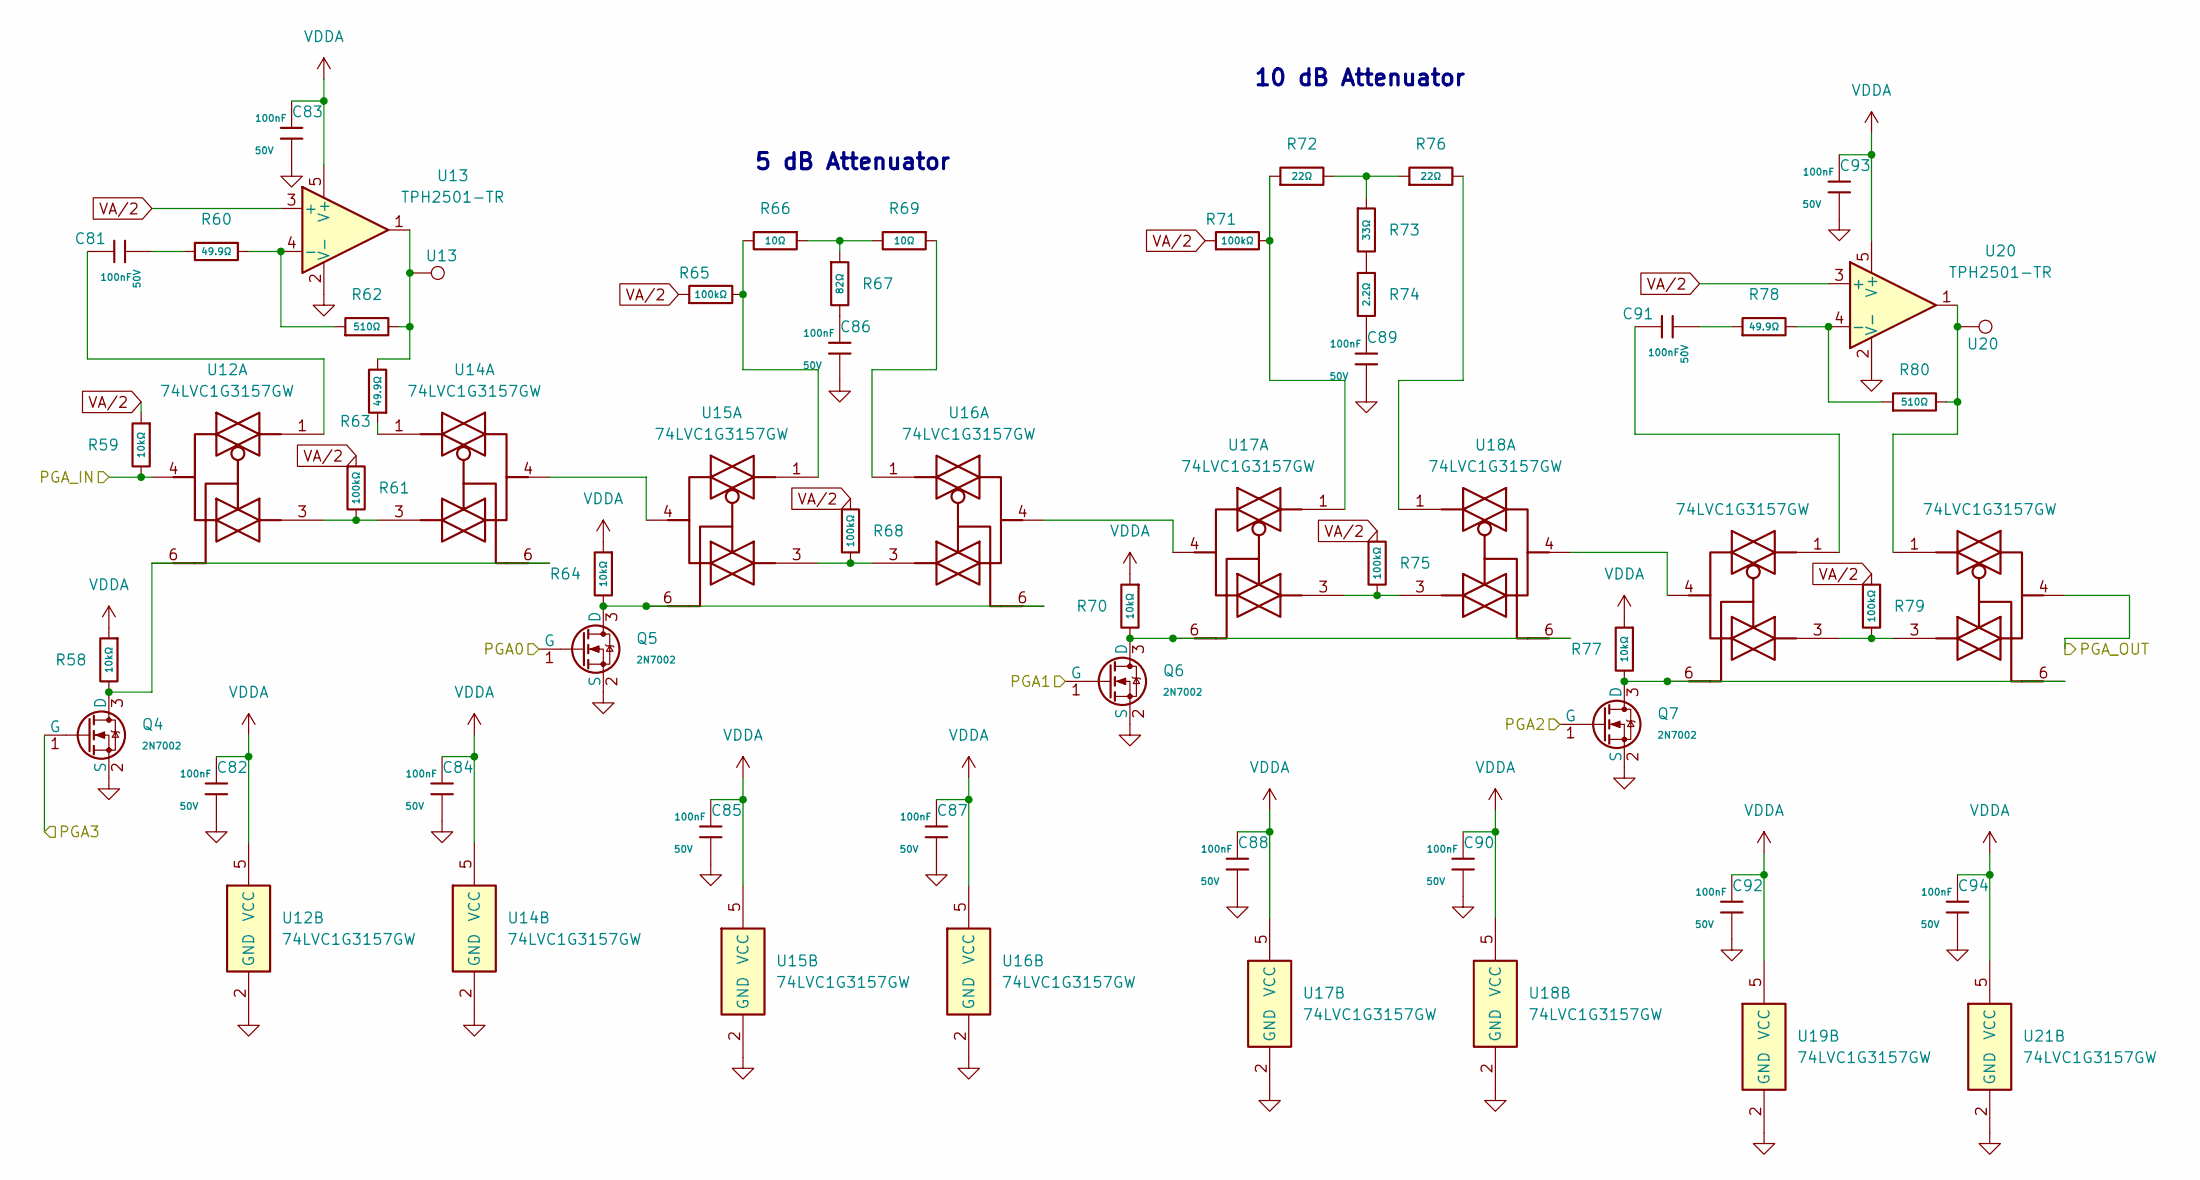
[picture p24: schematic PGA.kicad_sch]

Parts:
C81, C82, C83, C84, C85, C86, C87, C88, C89, C90, C91, C92, C93, C94: 100nF; C_0402; Voltage Rated 50V; Tolerance ±10%; Part CL05B104KB54PNC; LCSC C307331
Q4, Q5, Q6, Q7: 2N7002; Q_SOT-23; Part 2N7002K; LCSC C22379475
R58, R59, R64, R70, R77: 10kΩ; R_0402; Overload Voltage (Max) 50V; Tolerance ±1%; Part 0402WGF1002TCE; LCSC C25744
R60, R63, R78: 49.9Ω; R_0402; Overload Voltage (Max) 50V; Tolerance ±1%; Part 0402WGF499JTCE; LCSC C25120
R61, R65, R68, R71, R75, R79: 100kΩ; R_0402; Overload Voltage (Max) 50V; Tolerance ±1%; Part 0402WGF1003TCE; LCSC C25741
R62, R80: 510Ω; R_0402; Overload Voltage (Max) 50V; Tolerance ±1%; Part 0402WGF5100TCE; LCSC C25123
R66, R69: 10Ω; R_0402; Overload Voltage (Max) 50V; Tolerance ±1%; Part 0402WGF100JTCE; LCSC C25077
R67: 82Ω; R_0603; Overload Voltage (Max) 75V; Tolerance ±1%; Part 0603WAF820JT5E; LCSC C23255
R72, R76: 22Ω; R_0603; Overload Voltage (Max) 75V; Tolerance ±1%; Part 0603WAF220JT5E; LCSC C23345
R73: 33Ω; R_0805; Overload Voltage (Max) 150V; Tolerance ±1%; Part 0805W8F330JT5E; LCSC C17634
R74: 2.2Ω; R_0603; Overload Voltage (Max) 75V; Tolerance ±1%; Part 0603WAF220KT5E; LCSC C22939
TP10: U13; TestPoint_THTPad_D2.5mm_Drill1.2mm
TP11: U20; TestPoint_THTPad_D2.5mm_Drill1.2mm
U12, U14, U15, U16, U17, U18, U19, U21: 74LVC1G3157GW; SOT-363_SC-70-6; LCSC C52140494
U13, U20: TPH2501-TR; SOT-23-5; LCSC C126713

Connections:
/Filter Playground/RX_OUT: R59.2, U12.4; also elsewhere on the board
/PGA0: Q5.1 (G); also elsewhere on the board
/PGA1: Q6.1 (G); also elsewhere on the board
/PGA2: Q7.1 (G); also elsewhere on the board
/PGA3: Q4.1 (G); also elsewhere on the board
/RX_OUT: U21.4; also elsewhere on the board
GND: C82.2, C83.2, C84.2, C85.2, C86.2, C87.2, C88.2, C89.2, C90.2, C92.2, C93.2, C94.2, Q4.2 (S), Q5.2 (S), Q6.2 (S), Q7.2 (S), U12.2 (GND), U13.2 (V-), U14.2 (GND), U15.2 (GND), U16.2 (GND), U17.2 (GND), U18.2 (GND), U19.2 (GND), U20.2 (V-), U21.2 (GND); also elsewhere on the board
unnamed: C81.1, U12.1
unnamed: C81.2, R60.1
unnamed: C86.1, R67.2
unnamed: C89.1, R74.2
unnamed: C91.1, U19.1
unnamed: C91.2, R78.1
unnamed: Q4.3 (D), R58.2, U12.6, U14.6
unnamed: Q5.3 (D), R64.2, U15.6, U16.6
unnamed: Q6.3 (D), R70.2, U17.6, U18.6
unnamed: Q7.3 (D), R77.2, U19.6, U21.6
unnamed: R61.2, U12.3, U14.3
unnamed: R62.2, R63.2, TP10.1 (1_1), U13.1
unnamed: R63.1, U14.1
unnamed: R65.2, R66.2, U15.1
unnamed: R66.1, R67.1, R69.2
unnamed: R68.2, U15.3, U16.3
unnamed: R69.1, U16.1
unnamed: R71.2, R72.1, U17.1
unnamed: R72.2, R73.1, R76.1
unnamed: R73.2, R74.1
unnamed: R75.2, U17.3, U18.3
unnamed: R76.2, U18.1
unnamed: R79.2, U19.3, U21.3
unnamed: R80.2, TP11.1 (1_1), U20.1, U21.1
unnamed: R60.2, R62.1, U13.4 (-)
unnamed: U14.4, U15.4
unnamed: U16.4, U17.4
unnamed: U18.4, U19.4
unnamed: R78.2, R80.1, U20.4 (-)
VA/2: R59.1, R61.1, R65.1, R68.1, R71.1, R75.1, R79.1, U13.3 (+), U20.3 (+); also elsewhere on the board
VDDA: C82.1, C83.1, C84.1, C85.1, C87.1, C88.1, C90.1, C92.1, C93.1, C94.1, R58.1, R64.1, R70.1, R77.1, U12.5 (VCC), U13.5 (V+), U14.5 (VCC), U15.5 (VCC), U16.5 (VCC), U17.5 (VCC), U18.5 (VCC), U19.5 (VCC), U20.5 (V+), U21.5 (VCC); also elsewhere on the board

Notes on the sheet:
5 dB Attenuator
10 dB Attenuator

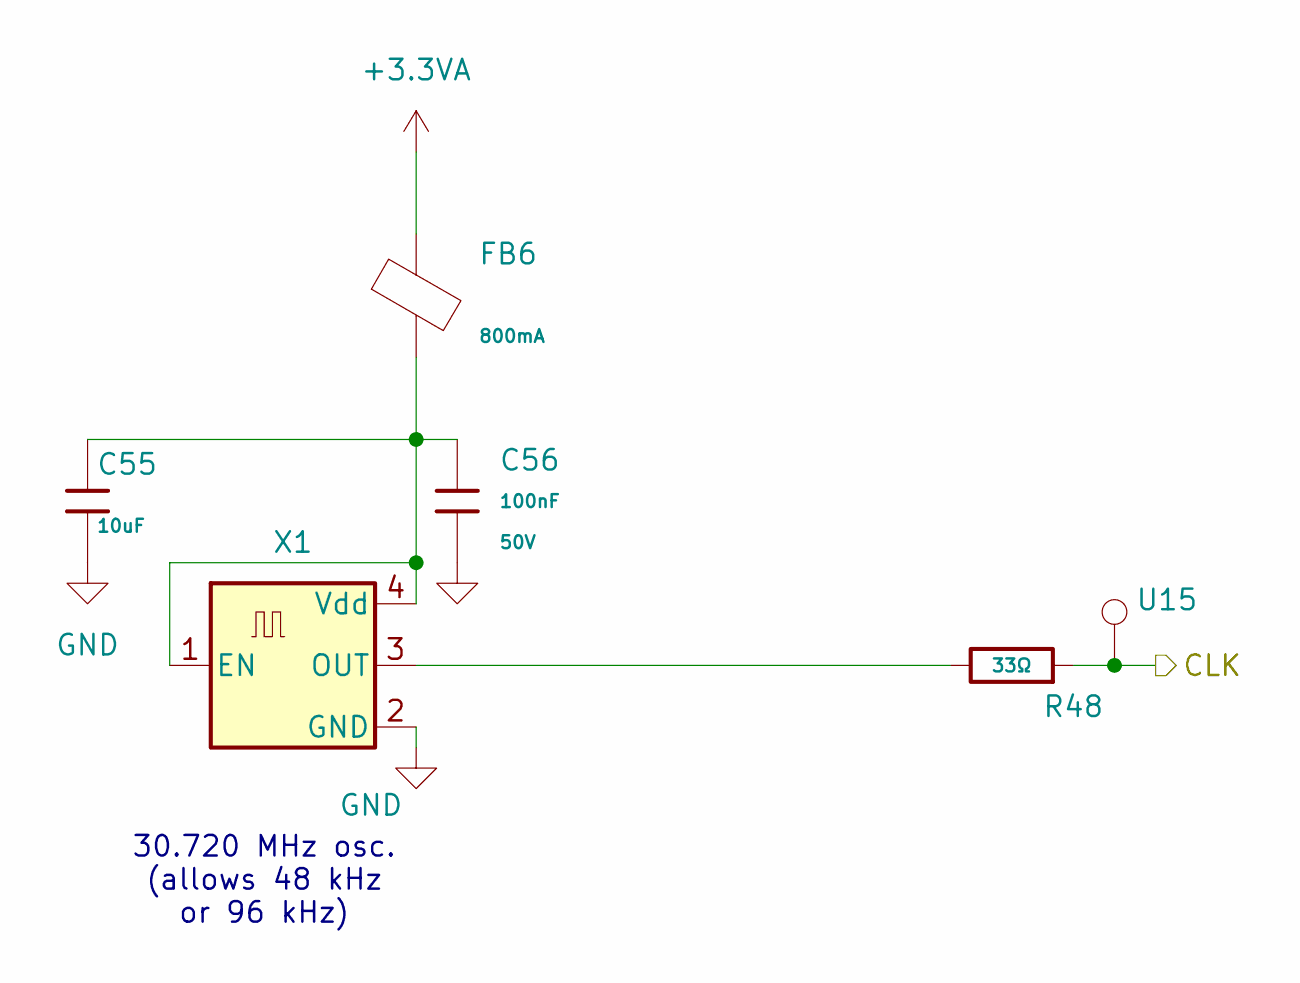
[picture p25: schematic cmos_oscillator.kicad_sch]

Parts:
C55: 10uF; C_0805; Voltage Rated 50V; Tolerance ±10%; Part GRM21BR61H106KE43L; LCSC C440198
C56: 100nF; C_0402; Voltage Rated 50V; Tolerance ±10%; Part CL05B104KB54PNC; LCSC C307331
FB6: FB_0805; Current Rating 800mA; Tolerance ±25%; Part GZ2012D101TF; LCSC C1015
R48: 33Ω; R_0805; Overload Voltage (Max) 150V; Tolerance ±1%; Part 0805W8F330JT5E; LCSC C17634
TP16: U15; TestPoint_THTPad_D2.5mm_Drill1.2mm
X1: SG-8018CE 30.720000MHz TJHPA; Oscillator_SMD_Abracon_ASE-4Pin_3.2x2.5mm; LCSC C390505

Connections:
+3.3VA: FB6.1; also elsewhere on the board
/CLK: R48.1, TP16.1 (1_1); also elsewhere on the board
GND: C55.2, C56.2, X1.2 (GND); also elsewhere on the board
unnamed: C55.1, C56.1, FB6.2, X1.1 (EN), X1.4 (Vdd)
unnamed: R48.2, X1.3 (OUT)

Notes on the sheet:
30.720 MHz osc. (allows 48 kHz or 96 kHz)

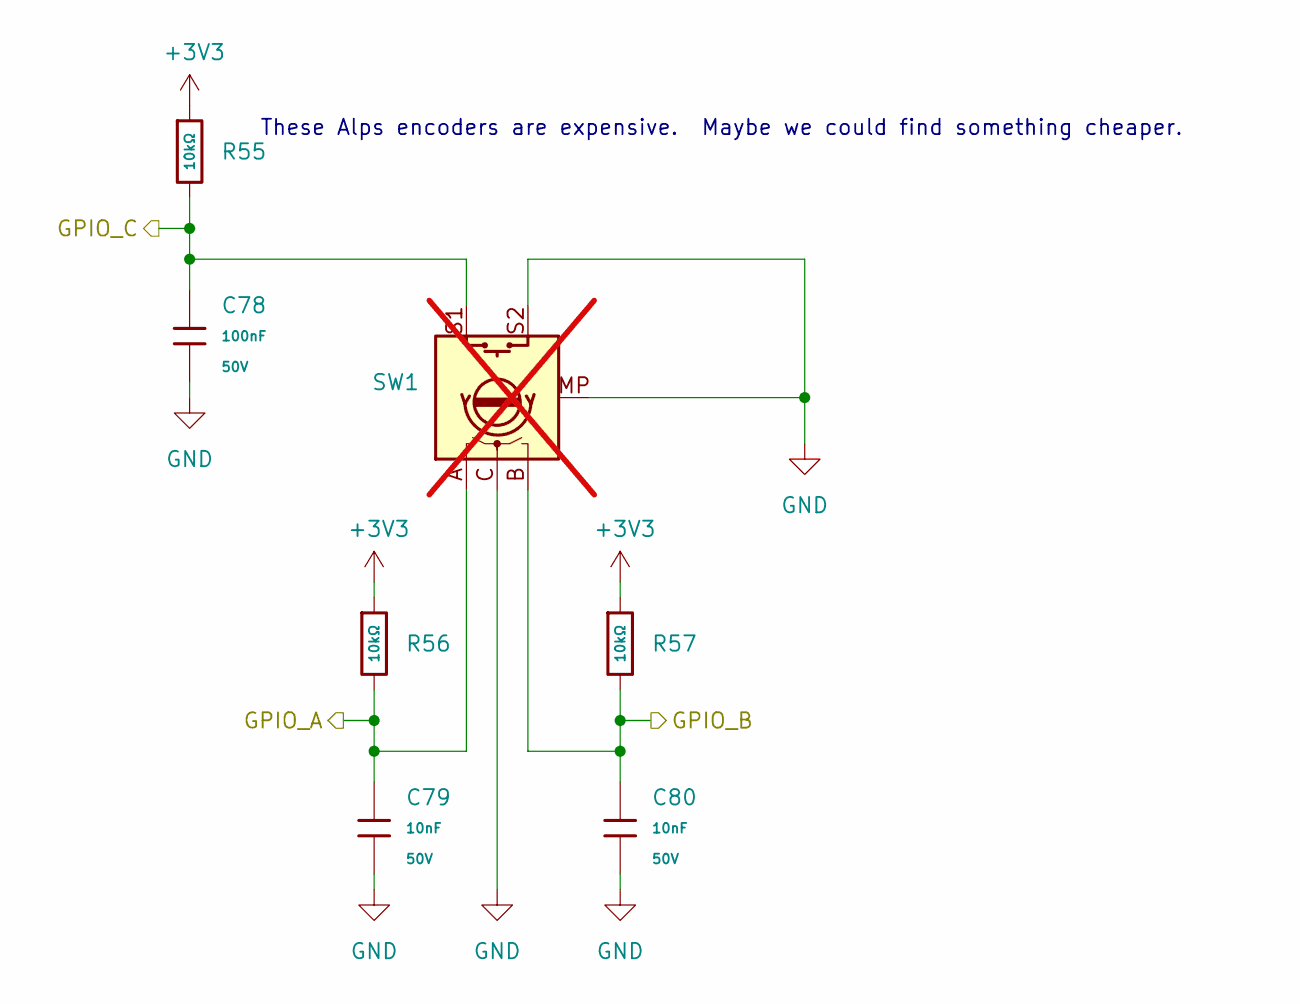
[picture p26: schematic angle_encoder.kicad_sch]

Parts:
C78: 100nF; C_0402; Voltage Rated 50V; Tolerance ±10%; Part CL05B104KB54PNC; LCSC C307331
C79, C80: 10nF; C_0402; Voltage Rated 50V; Tolerance ±10%; Part CL05B103KB5NNNC; LCSC C15195
R55, R56, R57: 10kΩ; R_0402; Overload Voltage (Max) 50V; Tolerance ±1%; Part 0402WGF1002TCE; LCSC C25744
SW1: RotaryEncoder_Switch_MP; RotaryEncoder_Alps_EC11E-Switch_Vertical_H20mm; LCSC C202365; not fitted

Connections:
+3V3: R55.1, R56.1, R57.1; also elsewhere on the board
/ANG_0: C79.1, R56.2, SW1.A; also elsewhere on the board
/ANG_1: C80.1, R57.2, SW1.B; also elsewhere on the board
/ANG_2: C78.1, R55.2, SW1.S1; also elsewhere on the board
GND: C78.2, C79.2, C80.2, SW1.C, SW1.MP, SW1.S2; also elsewhere on the board

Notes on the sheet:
These Alps encoders are expensive. Maybe we could find something cheaper.

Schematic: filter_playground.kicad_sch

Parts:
C95, C96, C97, C98, C99, C100, C101, C102, C103, C104, C105: 100nF; C_0402; Voltage Rated 50V; Tolerance ±10%; Part CL05B104KB54PNC; LCSC C307331
J10: SDR ANT; Conn_Coaxial_Frohne; not fitted
Je5, Je6: Filter; PinHeader_1x04_P2.54mm_Vertical; LCSC C2718488
Q8, Q9: 2N7002; Q_SOT-23; Part 2N7002K; LCSC C22379475
R81, R84, R87, R88: 10kΩ; R_0402; Overload Voltage (Max) 50V; Tolerance ±1%; Part 0402WGF1002TCE; LCSC C25744
R82, R83, R85, R86: 100kΩ; R_0402; Overload Voltage (Max) 50V; Tolerance ±1%; Part 0402WGF1003TCE; LCSC C25741
TP12, TP13, TP17, TP18: GND; TestPoint_THTPad_D2.5mm_Drill1.2mm
TR4: H1102NLT; Transformer_Ethernet_Wuerth_749013011A; LCSC C20623173
U22, U23, U24: 74LVC1G3157GW; SOT-363_SC-70-6; LCSC C52140494

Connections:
/BAND_SW: Q8.1 (G); also elsewhere on the board
/Filter Playground/RX_OUT: C104.2; also elsewhere on the board
/TX_SDR: C105.2; also elsewhere on the board
/~T/R: Q9.1 (G); also elsewhere on the board
GND: C97.2, C100.2, C103.2, Je5.2, Je5.3, Je6.2, Je6.3, Q8.2 (S), Q9.2 (S), TP12.1 (1_1), TP13.1 (1_1), TP17.1 (1_1), TP18.1 (1_1), TR4.6 (RD+), U22.2 (GND), U23.2 (GND), U24.2 (GND); also elsewhere on the board
unnamed: C96.2, R81.2, U22.4
unnamed: C98.1, R82.2, U22.1
unnamed: C99.1, R83.2, U22.3
unnamed: C101.2, R85.2, U23.1
unnamed: C102.2, R86.2, U23.3
unnamed: C104.1, U24.3
unnamed: C105.1, U24.1
unnamed: J10.2 (Ext), TR4.11 (RX+)
unnamed: C95.1, J10.1 (In)
unnamed: C98.2, Je5.1
unnamed: C101.1, Je5.4
unnamed: C99.2, Je6.1
unnamed: C102.1, Je6.4
unnamed: Q8.3 (D), R84.2, U22.6, U23.6
unnamed: Q9.3 (D), R88.2, U24.6
unnamed: R87.2, U23.4, U24.4
unnamed: C96.1, TR4.8 (RD-)
unnamed: C95.2, TR4.9 (RX-)
VA/2: R81.1, R82.1, R83.1, R85.1, R86.1, R87.1; also elsewhere on the board
VDDA: C97.1, C100.1, C103.1, R84.1, R88.1, U22.5 (VCC), U23.5 (VCC), U24.5 (VCC); also elsewhere on the board

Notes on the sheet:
Filters
T/R Switch
Scope GND connections

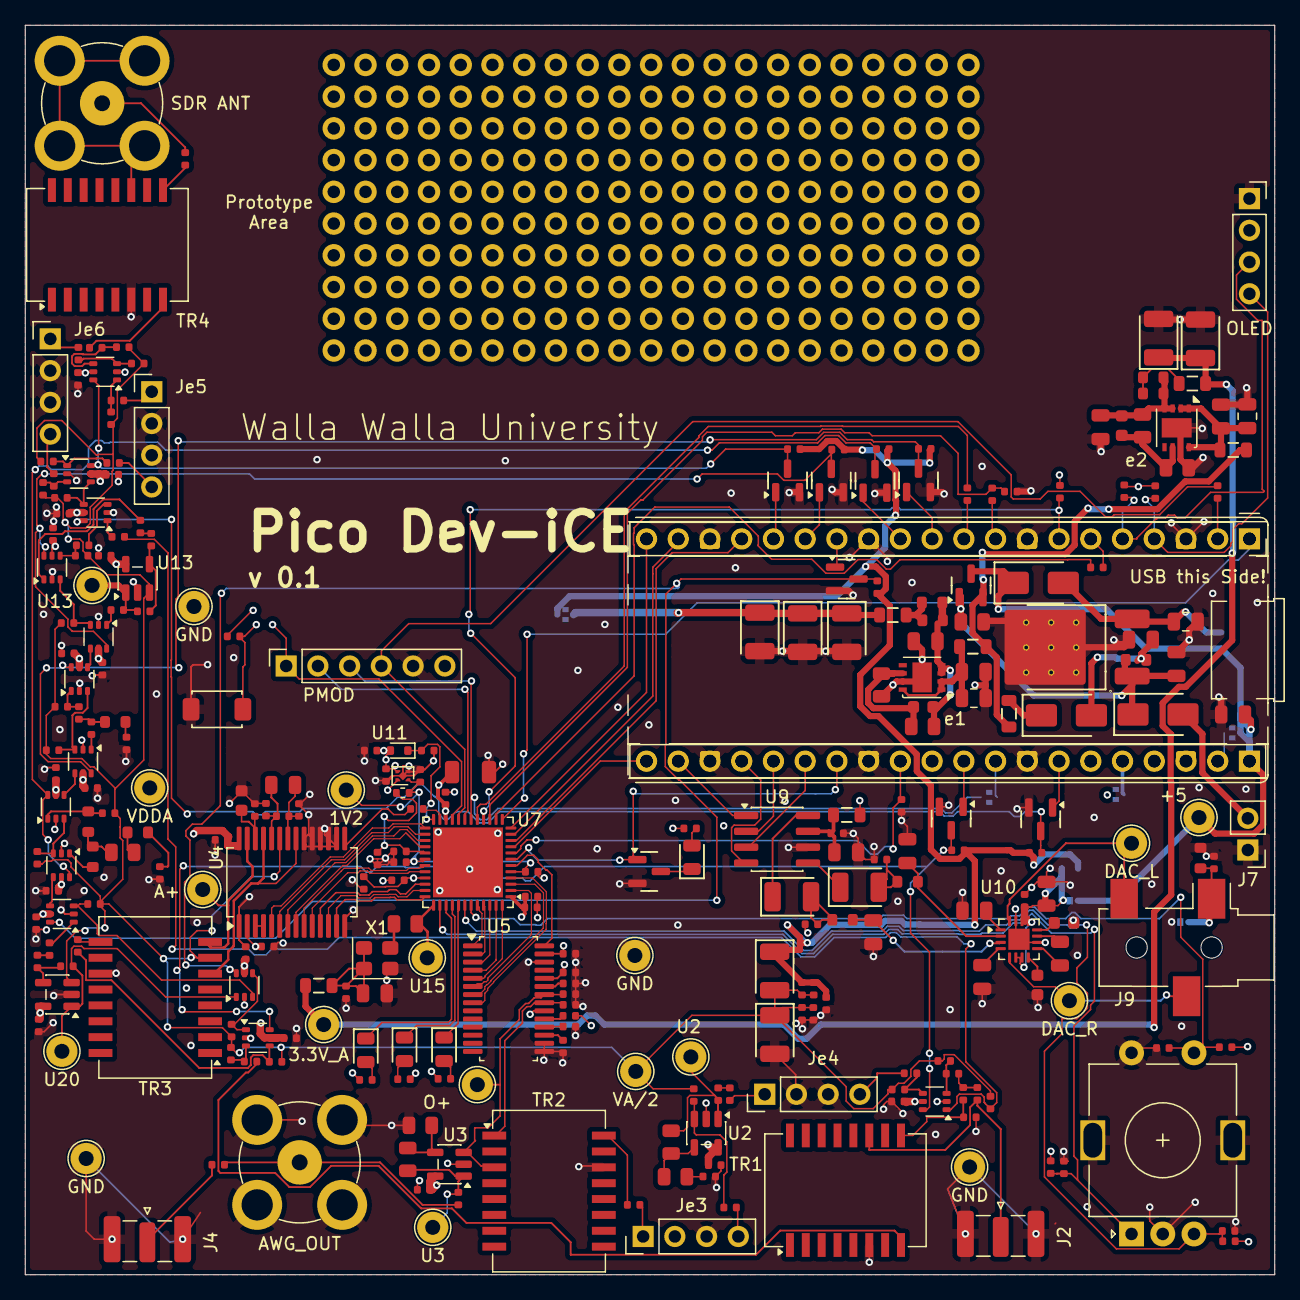
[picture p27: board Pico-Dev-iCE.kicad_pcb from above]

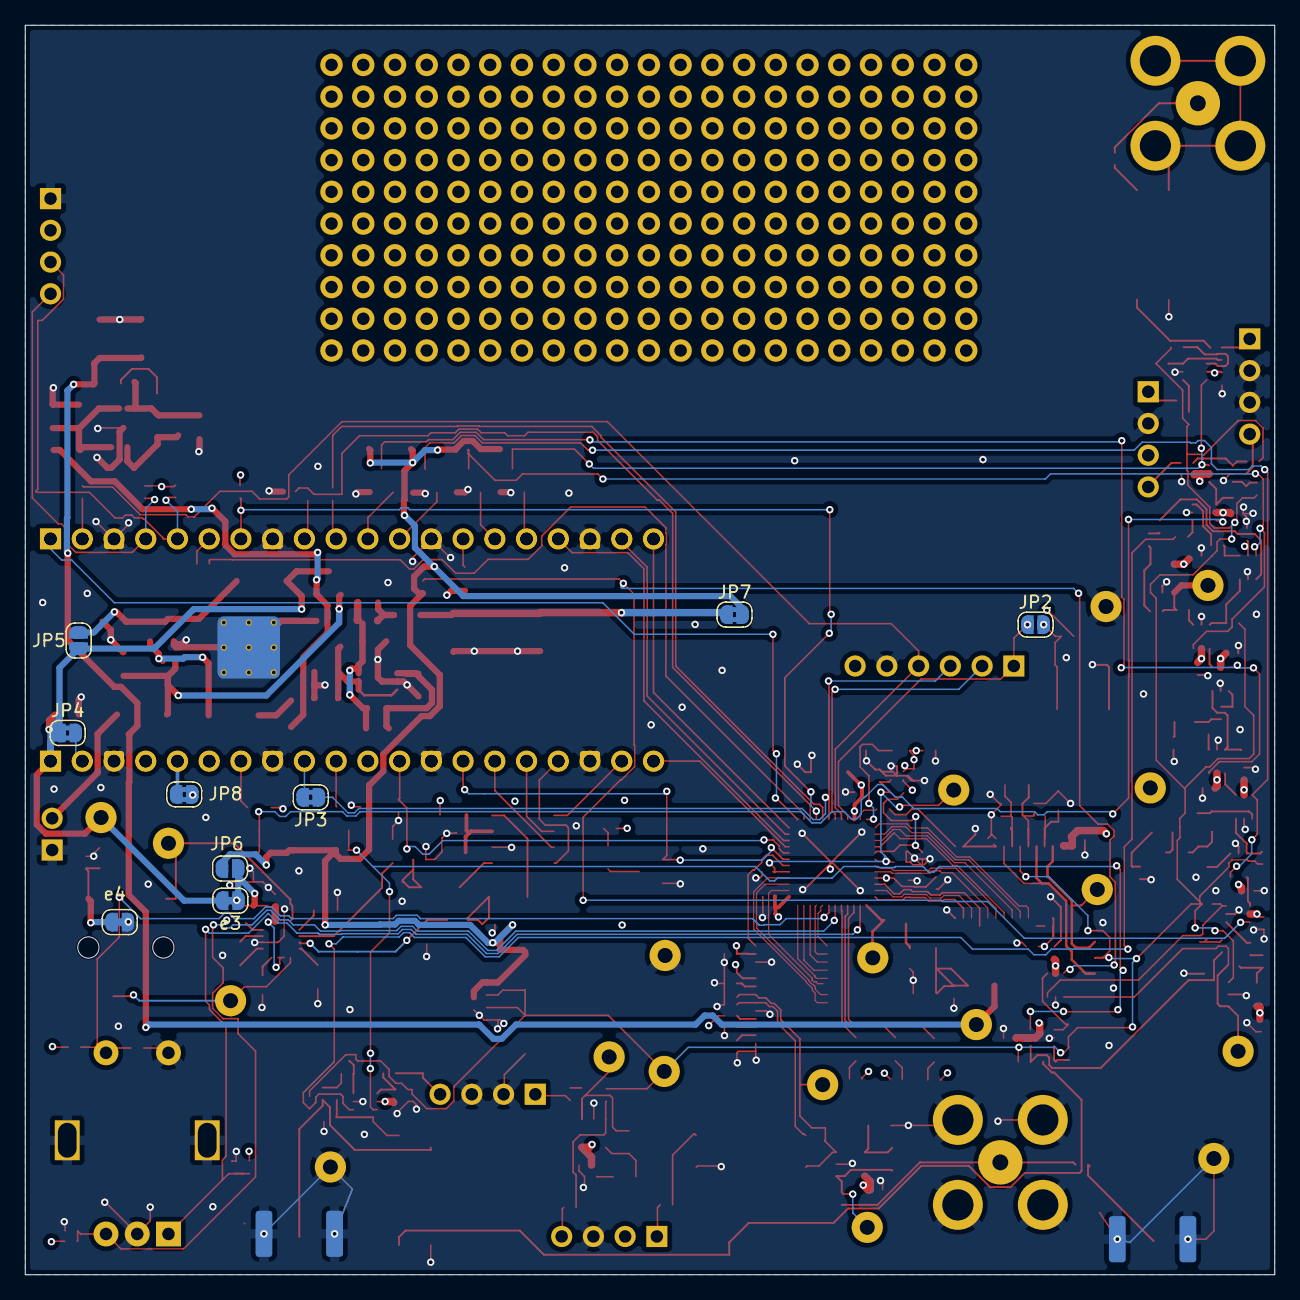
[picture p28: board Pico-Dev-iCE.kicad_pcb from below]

Board: 4 copper layers, 100.0 x 100.0 mm, 294 parts (9 on the bottom side), 199 nets.

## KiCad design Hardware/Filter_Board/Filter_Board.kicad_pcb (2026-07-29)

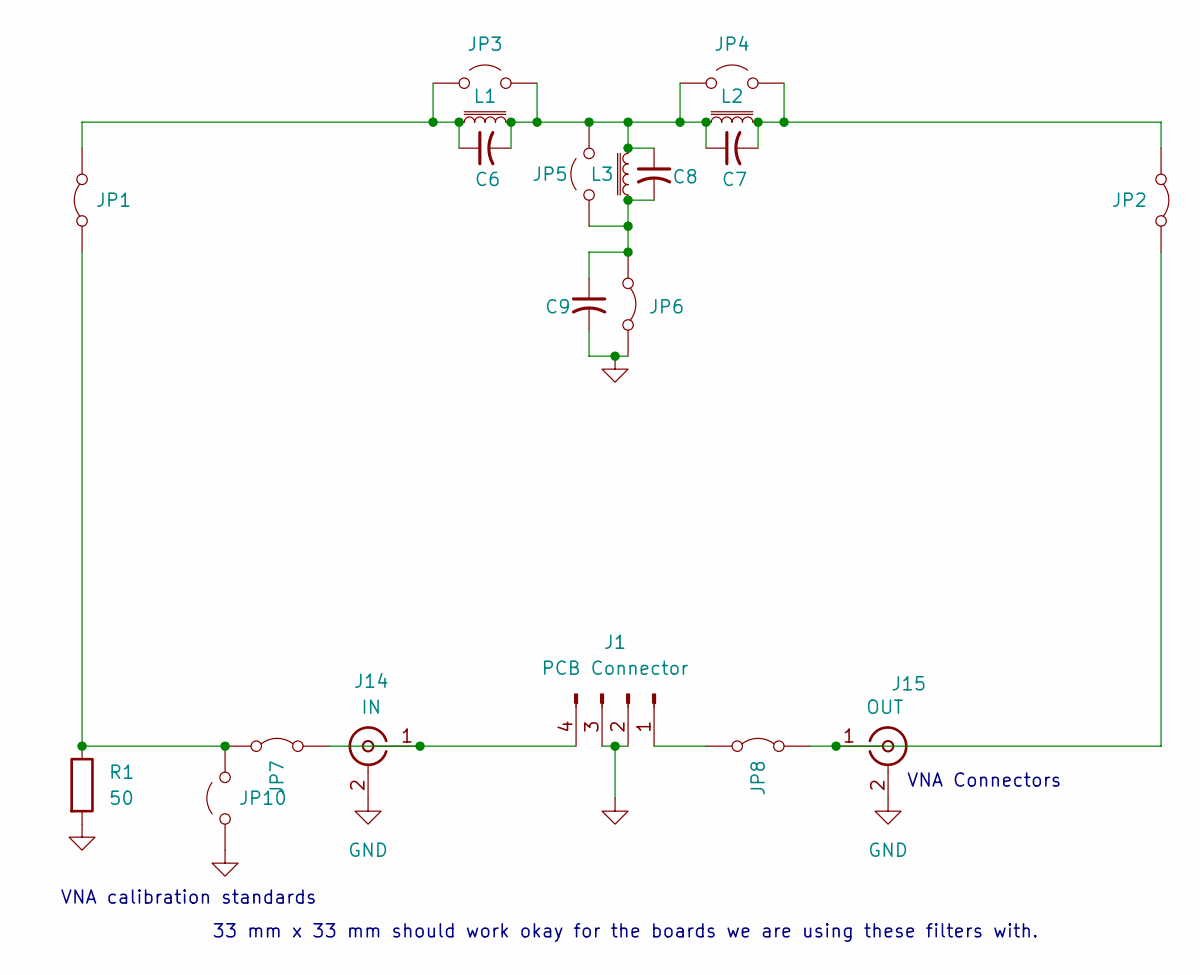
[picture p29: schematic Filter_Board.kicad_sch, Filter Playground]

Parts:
C6, C7, C8, C9: C_Small_US; Capacitor_multi_no_trimmer
J1: PCB Connector; PinHeader_1x04_P2.54mm_Horizontal
J14: IN; SMA_Amphenol_132289_EdgeMount
J15: OUT; SMA_Amphenol_132289_EdgeMount
JP1, JP2, JP6, JP7, JP8: Jumper_2_Bridged; SolderJumper-2_P1.3mm_Bridged_RoundedPad1.0x1.5mm
JP3, JP4, JP5, JP10: Jumper_2_Open; SolderJumper-2_P1.3mm_Open_RoundedPad1.0x1.5mm
L1, L2, L3: L_Iron_Small; Inductor_Multi
R1: 50; C_0805_2012Metric_Pad1.18x1.45mm_HandSolder

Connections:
GND: C9.2, J1.2, J1.3, J14.2 (Ext), J15.2 (Ext), JP6.1 (A), JP10.1 (A), R1.2
unnamed: J1.1, JP8.2 (B)
unnamed: J1.4, J14.1 (In), JP7.1 (A)
unnamed: J15.1 (In), JP2.1 (A), JP8.1 (A)
unnamed: JP1.1 (A), JP7.2 (B), JP10.2 (B), R1.1
unnamed: C6.1, JP1.2 (B), JP3.1 (A), L1.1
unnamed: C7.2, JP2.2 (B), JP4.2 (B), L2.2
unnamed: C6.2, C7.1, C8.1, JP3.2 (B), JP4.1 (A), JP5.1 (A), L1.2, L2.1, L3.1
unnamed: C8.2, C9.1, JP5.2 (B), JP6.2 (B), L3.2

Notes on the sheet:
VNA Connectors
33 mm x 33 mm should work okay for the boards we are using these filters with.
VNA calibration standards

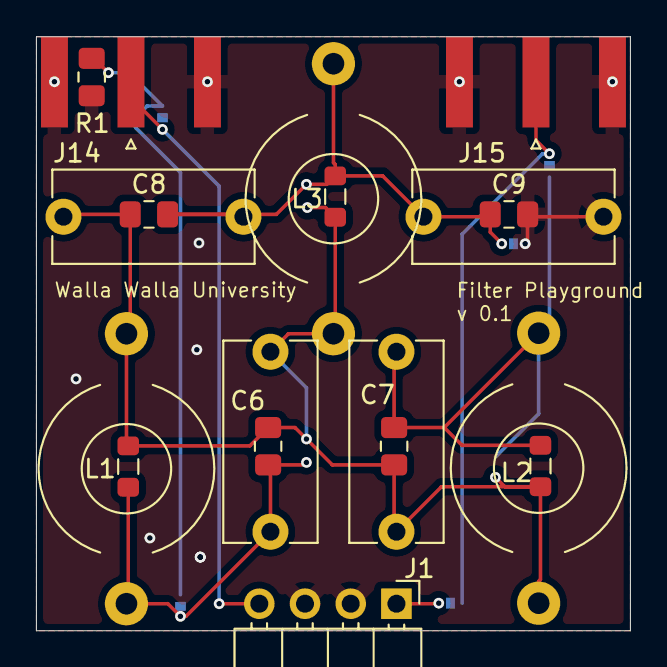
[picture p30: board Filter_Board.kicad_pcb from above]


Board: 2 copper layers, 33.0 x 33.0 mm, 20 parts (9 on the bottom side), 9 nets.

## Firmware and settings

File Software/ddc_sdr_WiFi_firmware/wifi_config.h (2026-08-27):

#ifndef WIFI_CONFIG_H
#define WIFI_CONFIG_H

#define DEFAULT_WIFI_SSID_PRIMARY   "Frohne-Shop-2.4GHz"
#define DEFAULT_WIFI_SSID_SECONDARY "Frohne-2.4GHz"
#define DEFAULT_WIFI_PASSWORD       ""

#define STATIC_FALLBACK_IP          "192.168.1.191"
#define STATIC_FALLBACK_NETMASK     "255.255.255.0"
#define STATIC_FALLBACK_GATEWAY     "192.168.1.1"

#define TCP_CONTROL_PORT            5000

#endif // WIFI_CONFIG_H

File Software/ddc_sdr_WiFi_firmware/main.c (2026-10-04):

#include <stdbool.h>
#include <stddef.h>
#include <stdint.h>
#include <stdio.h>
#include <stdlib.h>
#include <string.h>

#include "hardware/clocks.h"
#include "hardware/dma.h"
#include "hardware/gpio.h"
#include "hardware/irq.h"
#include "hardware/pio.h"
#include "hardware/spi.h"
#include "hardware/sync.h"
#include "hardware/vreg.h"
#include "pico/stdlib.h"
#include "pico/bootrom.h"
#include "pico/multicore.h"

#include "pico/cyw43_arch.h"
#include "cyw43_internal.h"
#include "openhpsdr.h"
#include "wifi_config.h"
#include "lwip/dhcp.h"

#include "boards.h"
#include "agc_control.h"
#include "ddc_protocol.h"
#include "ice_cram.h"
#include "ice_fpga.h"
#include "ice_fpga_data.h"
#include "ice_spi.h"
#include "i2s_rx.pio.h"
#ifdef DDC_HAS_STORED_RX
#include "fpga_bitstream_rx.h"
#endif

#define DDC_I2S_DATA_PIN 14
#define DDC_I2S_BCK_PIN 15
#define DDC_I2S_WS_PIN 16
#define DDC_TR_PIN 28
#define DDC_REF_PIN 26
#define DDC_FPGA_INT_PIN 0
#define DDC_PGA_GPIO_BASE 8
#define DDC_PGA_GPIO_COUNT 4
#define DDC_DEFAULT_SAMPLE_RATE 48000u
#define DDC_RUNTIME_SPI_BAUD_HZ 10000000u
#define DDC_MAX_WORDS_PER_BUFFER 256u

#define DDC_AUDIO_RING_COUNT 64u
static uint32_t audio_ring[DDC_AUDIO_RING_COUNT][DDC_MAX_WORDS_PER_BUFFER];
static volatile uint8_t ring_write_idx = 0;
static volatile uint8_t ring_read_idx = 0;
static volatile uint32_t ring_overruns = 0;

static uint g_pio_offset;
static int dma_channel_a = -1;
static int dma_channel_b = -1;
static const uint32_t words_per_buffer = HPSDR_WORDS_PER_PACKET;

static bool i2s_running = false;
static bool runtime_spi_ready = false;
static bool fpga_ready = false;
static uint32_t sample_rate = DDC_DEFAULT_SAMPLE_RATE;
static volatile bool fpga_interrupt_pending = false;
static ddc_agc_state_t agc_state;
static uint32_t last_frequency_hz = 7050000u;
static uint32_t freq_cmd_count = 0;

static const char *s_current_ssid = DEFAULT_WIFI_SSID_PRIMARY;
static bool s_ip_configured = false;
static uint32_t s_noip_since = 0;

static bool fpga_write_command(uint8_t command, uint32_t value);
static bool fpga_set_frequency(uint32_t frequency_hz);
static void pga_set_code(uint8_t code);
static bool apply_sample_rate(uint32_t rate);
static void i2s_start(void);
static void i2s_stop(void);

static volatile uint32_t s_pending_freq = 0;
static volatile uint32_t s_pending_rate = 0;
static volatile int8_t s_pending_gain = -1;

static void on_hpsdr_freq_change(uint32_t freq_hz) {
    s_pending_freq = freq_hz;
}

static void on_hpsdr_rate_change(uint32_t rate_hz) {
    s_pending_rate = rate_hz;
}

static void on_hpsdr_gain_change(uint8_t pga_code) {
    s_pending_gain = (int8_t)pga_code;
}

static void tr_set_receive(bool receive)
{
    gpio_put(DDC_TR_PIN, receive ? 1u : 0u);
}

static void pga_set_code(uint8_t code)
{
    code &= DDC_PGA_MAX_CODE;
    for (uint gpio = DDC_PGA_GPIO_BASE;
         gpio < DDC_PGA_GPIO_BASE + DDC_PGA_GPIO_COUNT;
         gpio++) {
        gpio_put(gpio, (code >> (gpio - DDC_PGA_GPIO_BASE)) & 1u);
    }
}

static void fpga_interrupt_handler(uint gpio, uint32_t events)
{
    (void)events;
    if (gpio == DDC_FPGA_INT_PIN) {
        fpga_interrupt_pending = true;
    }
}

static void handle_fpga_interrupt(void)
{
    if (!fpga_interrupt_pending || !fpga_ready || !runtime_spi_ready) {
        return;
    }

    fpga_interrupt_pending = false;
    if (ddc_agc_on_otr(&agc_state))
        pga_set_code(agc_state.pga_code);
    fpga_write_command(DDC_FPGA_CMD_CLEAR_OTR, 1u);
}

static void agc_task(void)
{
    bool fpga_int_high;
    uint64_t now_ms;

    if (!fpga_ready)
        return;

    fpga_int_high = gpio_get(DDC_FPGA_INT_PIN);
    now_ms = time_us_64() / 1000u;
    if (ddc_agc_tick(&agc_state, fpga_int_high, now_ms))
        pga_set_code(agc_state.pga_code);
}

static volatile uint32_t dma_a_irq_count = 0;
static volatile uint32_t dma_b_irq_count = 0;

static void dma_handler(void)
{
    uint32_t status = dma_hw->ints0;

    if (status & (1u << dma_channel_a)) {
        dma_hw->ints0 = 1u << dma_channel_a;
        dma_a_irq_count++;
        uint8_t next_write = (ring_write_idx + 1u) % DDC_AUDIO_RING_COUNT;
        if (next_write == ring_read_idx) {
            ring_overruns++;
            ring_read_idx = (ring_read_idx + 1u) % DDC_AUDIO_RING_COUNT;
        }
        ring_write_idx = next_write;

        // Channel A runs on even slots (0, 2, 4, 6...): arm next even slot
        uint8_t next_a = (ring_write_idx + 1u) % DDC_AUDIO_RING_COUNT;
        dma_channel_set_write_addr(dma_channel_a, audio_ring[next_a], false);
        dma_channel_set_trans_count(dma_channel_a, words_per_buffer, false);
    }
    if (status & (1u << dma_channel_b)) {
        dma_hw->ints0 = 1u << dma_channel_b;
        dma_b_irq_count++;
        uint8_t next_write = (ring_write_idx + 1u) % DDC_AUDIO_RING_COUNT;
        if (next_write == ring_read_idx) {
            ring_overruns++;
            ring_read_idx = (ring_read_idx + 1u) % DDC_AUDIO_RING_COUNT;
        }
        ring_write_idx = next_write;

        // Channel B runs on odd slots (1, 3, 5, 7...): arm next odd slot
        uint8_t next_b = (ring_write_idx + 1u) % DDC_AUDIO_RING_COUNT;
        dma_channel_set_write_addr(dma_channel_b, audio_ring[next_b], false);
        dma_channel_set_trans_count(dma_channel_b, words_per_buffer, false);
    }
}

static void i2s_configure(void)
{
    pio_gpio_init(pio0, DDC_I2S_DATA_PIN);
    pio_gpio_init(pio0, DDC_I2S_BCK_PIN);
    pio_gpio_init(pio0, DDC_I2S_WS_PIN);
    gpio_pull_up(DDC_I2S_DATA_PIN);
    gpio_pull_up(DDC_I2S_BCK_PIN);
    gpio_pull_up(DDC_I2S_WS_PIN);
    pio_sm_set_consecutive_pindirs(pio0, 0, DDC_I2S_DATA_PIN, 3, false);

    pio_sm_config config = i2s_rx_program_get_default_config(g_pio_offset);
    sm_config_set_in_pins(&config, DDC_I2S_DATA_PIN);
    sm_config_set_in_shift(&config, false, true, 32);
    sm_config_set_clkdiv(&config, 1.0f);
    pio_sm_init(pio0, 0, g_pio_offset, &config);
}

static void i2s_stop(void)
{
    if (dma_channel_a < 0 || dma_channel_b < 0) {
        return;
    }

    dma_channel_abort(dma_channel_a);
    dma_channel_abort(dma_channel_b);
    dma_hw->ints0 = (1u << dma_channel_a) | (1u << dma_channel_b);
    pio_sm_set_enabled(pio0, 0, false);
    pio_sm_clear_fifos(pio0, 0);
    i2s_running = false;
    irq_set_enabled(DMA_IRQ_0, false);
}

static void i2s_start(void)
{
    if (i2s_running || !fpga_ready || !openhpsdr_is_active()) {
        return;
    }

    // Stop and clear PIO SM and FIFOs completely first
    pio_sm_set_enabled(pio0, 0, false);
    pio_sm_clear_fifos(pio0, 0);

    i2s_configure();

    // Reset PIO execution state to sync anchor at start of program
    pio_sm_restart(pio0, 0);
    pio_sm_exec(pio0, 0, pio_encode_jmp(g_pio_offset));
    pio_sm_clear_fifos(pio0, 0);

    // Initialize ring buffer pointers and arm slot 0 on channel A, slot 1 on channel B
    ring_write_idx = 0;
    ring_read_idx = 0;
    dma_channel_set_write_addr(dma_channel_a, audio_ring[0], false);
    dma_channel_set_trans_count(dma_channel_a, words_per_buffer, false);
    dma_channel_set_write_addr(dma_channel_b, audio_ring[1], false);
    dma_channel_set_trans_count(dma_channel_b, words_per_buffer, false);
    dma_hw->ints0 = (1u << dma_channel_a) | (1u << dma_channel_b);
    irq_set_enabled(DMA_IRQ_0, true);
    dma_channel_start(dma_channel_a);

    // NOW enable PIO state machine with guaranteed empty FIFO.
    // The PIO begins with wait 1 pin 2; wait 0 pin 2 (WS falling edge),
    // guaranteeing that word 0 received by DMA is ALWAYS Left (I).
    pio_sm_set_enabled(pio0, 0, true);
    i2s_running = true;
}

static void runtime_spi_stop(void)
{
    if (!runtime_spi_ready) {
        return;
    }

    ice_spi_chip_deselect(FPGA_DATA.bus.CS_cram);
    ice_spi_deinit();
    runtime_spi_ready = false;
}

static bool fpga_runtime_init(void)
{
    if (runtime_spi_ready) {
        return true;
    }

    ice_spi_init_cs_pin(FPGA_DATA.bus.CS_cram, false);
    runtime_spi_ready = ice_spi_init(FPGA_DATA.bus);
    if (runtime_spi_ready)
        spi_set_baudrate(FPGA_DATA.bus.peripheral, DDC_RUNTIME_SPI_BAUD_HZ);
    return runtime_spi_ready;
}

static bool fpga_write_command(uint8_t command, uint32_t value)
{
    uint8_t frame[DDC_FPGA_FRAME_HEADER_LEN + 4u];

    if (!runtime_spi_ready) {
        return false;
    }

    ddc_make_u32_command(frame, command, value);
    ice_spi_chip_select(FPGA_DATA.bus.CS_cram);
    ice_spi_write_blocking(frame, sizeof(frame));
    ice_spi_chip_deselect(FPGA_DATA.bus.CS_cram);
    return true;
}

static bool fpga_set_sample_rate(uint32_t rate)
{
    return fpga_write_command(DDC_FPGA_CMD_SET_SAMPLE_RATE, rate);
}

static bool fpga_set_frequency(uint32_t frequency_hz)
{
    if (frequency_hz == 0 || frequency_hz > DDC_FPGA_MAX_FREQUENCY_HZ) {
        return false;
    }
    return fpga_write_command(DDC_FPGA_CMD_SET_FREQUENCY,
                              ddc_frequency_to_fcw(frequency_hz));
}

static void pga_configure(void)
{
    ddc_agc_init(&agc_state);
    for (uint gpio = DDC_PGA_GPIO_BASE;
         gpio < DDC_PGA_GPIO_BASE + DDC_PGA_GPIO_COUNT;
         gpio++) {
        gpio_init(gpio);
        gpio_set_dir(gpio, GPIO_OUT);
    }
    pga_set_code(agc_state.pga_code);
}

static void fpga_interrupt_configure(void)
{
    gpio_init(DDC_FPGA_INT_PIN);
    gpio_set_dir(DDC_FPGA_INT_PIN, GPIO_IN);
    gpio_pull_down(DDC_FPGA_INT_PIN);
    gpio_set_irq_enabled_with_callback(DDC_FPGA_INT_PIN,
                                        GPIO_IRQ_EDGE_RISE,
                                        true,
                                        fpga_interrupt_handler);
}

static bool configure_fpga_bitstream(const uint8_t *bitstream, size_t size)
{
    ice_fpga_init(FPGA_DATA, 48);
    ice_fpga_stop(FPGA_DATA);
    if (!ice_cram_open(FPGA_DATA)) {
        return false;
    }
    if (ice_cram_write(bitstream, size) < 0) {
        ice_cram_close();
        return false;
    }
    return ice_cram_close();
}

static bool configure_stored_fpga(void)
{
#ifdef DDC_HAS_STORED_RX
    return configure_fpga_bitstream(ddc_fpga_rx_bitstream, DDC_FPGA_RX_BITSTREAM_SIZE);
#else
    return false;
#endif
}

static bool restore_fpga_runtime(void)
{
    if (!fpga_runtime_init()) {
        return false;
    }

    fpga_ready = true;
    fpga_set_sample_rate(sample_rate);
    fpga_set_frequency(last_frequency_hz);
    i2s_start();
    return true;
}

static bool apply_sample_rate(uint32_t rate)
{
    bool was_running;

    if (rate != 48000u && rate != 96000u) {
        return false;
    }
    if (!fpga_ready) {
        return false;
    }
    if (rate == sample_rate) {
        return true;
    }

    was_running = i2s_running;
    if (was_running) {
        i2s_stop();
    }
    if (!fpga_set_sample_rate(rate)) {
        if (was_running) {
            i2s_start();
        }
        return false;
    }

    sample_rate = rate;
    if (was_running) {
        i2s_start();
    }
    return true;
}

static void audio_task(void)
{
    if (!i2s_running || !openhpsdr_is_active()) {
        return;
    }

    int budget = 8;
    while (ring_read_idx != ring_write_idx && budget-- > 0) {
        if (!openhpsdr_can_send()) {
            break;
        }
        const uint32_t *source = audio_ring[ring_read_idx];
        openhpsdr_push_samples(source, words_per_buffer);
        ring_read_idx = (ring_read_idx + 1u) % DDC_AUDIO_RING_COUNT;
    }
}

uint32_t get_ring_overruns(void) {
    return ring_overruns;
}

uint32_t get_dma_irq_count(void) {
    return dma_a_irq_count + dma_b_irq_count;
}

int main(void)
{
    gpio_init(25);
    gpio_set_dir(25, GPIO_OUT);
    gpio_put(25, 1);

    gpio_init(DDC_TR_PIN);
    gpio_set_dir(DDC_TR_PIN, GPIO_OUT);
    tr_set_receive(true);

    gpio_init(DDC_REF_PIN);
    gpio_set_dir(DDC_REF_PIN, GPIO_OUT);
    gpio_put(DDC_REF_PIN, 0);

    // Hardware FPGA Reset: hold CRESET_B (GPIO 22) low to allow power rails to settle
    gpio_init(22);
    gpio_set_dir(22, GPIO_OUT);
    gpio_put(22, 0);
    sleep_ms(30);
    gpio_put(22, 1);
    sleep_ms(15);

    // CDONE pin (GPIO 21)
    gpio_init(21);
    gpio_set_dir(21, GPIO_IN);
    gpio_pull_up(21);

    vreg_set_voltage(VREG_VOLTAGE_1_15);
    set_sys_clock_khz(150000, true);

    g_pio_offset = pio_add_program(pio0, &i2s_rx_program);
    pga_configure();
    fpga_interrupt_configure();
    dma_channel_a = dma_claim_unused_channel(true);
    dma_channel_b = dma_claim_unused_channel(true);

    dma_channel_config config_a = dma_channel_get_default_config(dma_channel_a);
    channel_config_set_transfer_data_size(&config_a, DMA_SIZE_32);
    channel_config_set_read_increment(&config_a, false);
    channel_config_set_write_increment(&config_a, true);
    channel_config_set_dreq(&config_a, pio_get_dreq(pio0, 0, false));
    channel_config_set_chain_to(&config_a, dma_channel_b);
    dma_channel_configure(dma_channel_a, &config_a, audio_ring[0],
                          &pio0->rxf[0], words_per_buffer, false);

    dma_channel_config config_b = dma_channel_get_default_config(dma_channel_b);
    channel_config_set_transfer_data_size(&config_b, DMA_SIZE_32);
    channel_config_set_read_increment(&config_b, false);
    channel_config_set_write_increment(&config_b, true);
    channel_config_set_dreq(&config_b, pio_get_dreq(pio0, 0, false));
    channel_config_set_chain_to(&config_b, dma_channel_a);
    dma_channel_configure(dma_channel_b, &config_b, audio_ring[1],
                          &pio0->rxf[0], words_per_buffer, false);

    dma_channel_set_irq0_enabled(dma_channel_a, true);
    dma_channel_set_irq0_enabled(dma_channel_b, true);
    irq_set_exclusive_handler(DMA_IRQ_0, dma_handler);

#ifdef DDC_FPGA_BOOT_FROM_STORED
    fpga_ready = false;
    for (int retry = 0; retry < 5; retry++) {
        gpio_put(22, 0);
        sleep_ms(10);
        gpio_put(22, 1);
        sleep_ms(10);

        if (configure_stored_fpga()) {
            if (restore_fpga_runtime()) {
                fpga_ready = true;
                break;
            }
        }
        sleep_ms(50);
    }
#else
    fpga_ready = false;
#endif

    bool wifi_ok = false;
    if (cyw43_arch_init() == 0) {
        wifi_ok = true;
        cyw43_arch_enable_sta_mode();
        cyw43_wifi_pm(&cyw43_state, CYW43_NONE_PM);
        uint32_t auth = (DEFAULT_WIFI_PASSWORD[0] == '\0') ? CYW43_AUTH_OPEN : CYW43_AUTH_WPA2_AES_PSK;
        const char *pass_param = (DEFAULT_WIFI_PASSWORD[0] == '\0') ? NULL : DEFAULT_WIFI_PASSWORD;
        cyw43_arch_wifi_connect_async(s_current_ssid, pass_param, auth);
        openhpsdr_init(on_hpsdr_freq_change, on_hpsdr_rate_change, on_hpsdr_gain_change);
    }
    uint32_t last_led_poll = 0;
    uint32_t last_reconnect_ms = to_ms_since_boot(get_absolute_time());

    while (true) {
        cyw43_arch_poll();
        handle_fpga_interrupt();
        agc_task();
        audio_task();

        if (s_pending_freq != 0) {
            uint32_t freq = s_pending_freq;
            s_pending_freq = 0;
            if (fpga_ready) {
                fpga_set_frequency(freq);
                last_frequency_hz = freq;
                freq_cmd_count++;
            }
        }
        if (s_pending_gain >= 0) {
            uint8_t code = (uint8_t)s_pending_gain;
            s_pending_gain = -1;
            agc_state.pga_code = code;
            pga_set_code(code);
        }
        if (s_pending_rate != 0) {
            uint32_t rate = s_pending_rate;
            s_pending_rate = 0;
            if (rate == 48000u || rate == 96000u) {
                apply_sample_rate(rate);
            }
        }

        if (wifi_ok) {
            openhpsdr_task();
            static bool s_last_hpsdr = false;
            bool hpsdr_now = openhpsdr_is_active();
            if (hpsdr_now != s_last_hpsdr) {
                s_last_hpsdr = hpsdr_now;
                if (hpsdr_now) {
                    i2s_start();
                    cyw43_arch_gpio_put(CYW43_WL_GPIO_LED_PIN, 1);
                    cyw43_wifi_pm(&cyw43_state, CYW43_NONE_PM);
                } else {
                    i2s_stop();
                    cyw43_arch_gpio_put(CYW43_WL_GPIO_LED_PIN, 0);
                }
            } else {
                if (hpsdr_now && !i2s_running) {
                    i2s_start();
                } else if (!hpsdr_now && i2s_running) {
                    i2s_stop();
                }
            }

            uint32_t now_ms = to_ms_since_boot(get_absolute_time());
            bool active = openhpsdr_is_active();

            // Pause status and LED polling during active streaming to eliminate SPI bus contention
            if (!active && (now_ms - last_led_poll >= 500)) {
                last_led_poll = now_ms;
                cyw43_arch_lwip_begin();
                int st = cyw43_tcpip_link_status(&cyw43_state, CYW43_ITF_STA);
                static int s_last_led = -1;
                int led_val = 0;
                if (st == CYW43_LINK_UP) {
                    s_noip_since = 0;
                    static bool s_pm_disabled = false;
                    if (!s_pm_disabled) {
                        s_pm_disabled = true;
                        cyw43_wifi_pm(&cyw43_state, CYW43_NONE_PM);
                    }
                    last_reconnect_ms = now_ms;
                    led_val = (now_ms / 500) % 2;
                } else if (st == CYW43_LINK_JOIN || st == CYW43_LINK_NOIP) {
                    last_reconnect_ms = now_ms;
                    led_val = (now_ms / 250) % 2;
#ifdef STATIC_FALLBACK_IP
                    if (!s_ip_configured) {
                        if (s_noip_since == 0) s_noip_since = now_ms;
                        if (now_ms - s_noip_since >= 8000) {
                            s_ip_configured = true;
                            dhcp_stop(&cyw43_state.netif[CYW43_ITF_STA]);
                            ip4_addr_t ip, nm, gw;
                            ip4addr_aton(STATIC_FALLBACK_IP, &ip);
                            ip4addr_aton(STATIC_FALLBACK_NETMASK, &nm);
                            ip4addr_aton(STATIC_FALLBACK_GATEWAY, &gw);
                            netif_set_addr(&cyw43_state.netif[CYW43_ITF_STA], &ip, &nm, &gw);
                            netif_set_link_up(&cyw43_state.netif[CYW43_ITF_STA]);
                            netif_set_up(&cyw43_state.netif[CYW43_ITF_STA]);
                        }
                    }
#endif
                } else {
                    s_noip_since = 0;
                    s_ip_configured = false;
                    led_val = (now_ms / 1000) % 2;
                    if (now_ms - last_reconnect_ms >= 15000) {
                        last_reconnect_ms = now_ms;
                        uint32_t auth = (DEFAULT_WIFI_PASSWORD[0] == 0) ? CYW43_AUTH_OPEN : CYW43_AUTH_WPA2_AES_PSK;
                        const char *pass_param = (DEFAULT_WIFI_PASSWORD[0] == 0) ? NULL : DEFAULT_WIFI_PASSWORD;
                        cyw43_arch_wifi_connect_async(s_current_ssid, pass_param, auth);
                    }
                }
                if (led_val != s_last_led) {
                    s_last_led = led_val;
                    cyw43_arch_gpio_put(CYW43_WL_GPIO_LED_PIN, led_val);
                }
                cyw43_arch_lwip_end();
            }
        }
    }
}

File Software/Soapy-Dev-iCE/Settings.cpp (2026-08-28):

// Settings.cpp — Constructor, DDC & Si5351a frequency control, sample rate, PGA gain, and settings.
//
// Supports both:
//   - Pico-Dev-iCE FPGA DDC SDR (FREQ,<hz>, PGA,<code>, REF,<0|1>, 0-30 MHz)
//   - WWU 2026 Tayloe SDR (Si5351 multi-synth math, 0.5-30 MHz)

#include "Soapy2026SDR.hpp"
#include <SoapySDR/Logger.hpp>
#include <stdexcept>
#include <cmath>
#include <cstdlib>
#include <algorithm>
#include <sstream>

// ─── Constructor ─────────────────────────────────────────────────────────────

Soapy2026SDR::Soapy2026SDR(const SoapySDR::Kwargs &args)
    : _isDDC(false)
    , _johnsonMode(false)
    , _johnsonAvailable(false)
    , _crystalFreq(30720000.0)
    , _centerFreq(7100000.0)
    , _sdrMode("DDC")
    , _pgaCode(0)
    , _refMux(0)
    , _audio(nullptr)
    , _sampleRate(48000.0)
    , _audioDeviceName("DDC SDR 2026")
    , _ringHead(0), _ringTail(0), _ringCount(0), _ringOverflow(false)
{
    // Audio device name can be overridden via args
    if (args.count("audio_label"))
        _audioDeviceName = args.at("audio_label");

    // ── Open serial port ──────────────────────────────────────────────────
    _serialPath = args.count("serial_port") ? args.at("serial_port") : "";
    if (_serialPath.empty())
        throw std::runtime_error("Soapy2026SDR: no serial_port specified");

    if (!_serial.open(_serialPath, 115200))
        throw std::runtime_error("Soapy2026SDR: cannot open " + _serialPath);

    SoapySDR_logf(SOAPY_SDR_INFO, "2026SDR: opened serial %s", _serialPath.c_str());

    // ── Board reset + ready handshake ─────────────────────────────────────
    char ctrlcd[] = {0x03, 0x04, 0};
    _serial.writeLine(std::string(ctrlcd));
    _serial.flushInput();

    // Wait for "SDR ready"
    for (int i = 0; i < 30; i++) {
        std::string line = _serialReadLine(200);
        if (line.find("SDR ready") != std::string::npos) break;
    }

    // ── Query firmware parameters ─────────────────────────────────────────
    _firmwareVersion = _getParam("VER");
    SoapySDR_logf(SOAPY_SDR_INFO, "2026SDR: firmware %s", _firmwareVersion.c_str());

    std::string xtalStr = _getParam("XTAL");
    double xtal = std::atof(xtalStr.c_str());
    if (xtal > 0.0) _crystalFreq = xtal;
    SoapySDR_logf(SOAPY_SDR_INFO, "2026SDR: master clock %.3f Hz", _crystalFreq);

    std::string modeStr = _getParam("MODE");
    _sdrMode = modeStr.empty() ? "DIRECT" : modeStr;

    if (_sdrMode == "DDC" || _firmwareVersion.find("DDC") != std::string::npos) {
        _isDDC = true;
        if (!args.count("audio_label")) {
            _audioDeviceName = "DDC SDR 2026";
        }
        SoapySDR_logf(SOAPY_SDR_INFO, "2026SDR: detected Pico-Dev-iCE DDC architecture");
    } else {
        _isDDC = false;
        _johnsonMode      = (_sdrMode == "JOHNSON");
        _johnsonAvailable = (_sdrMode == "JOHNSON");
        if (!args.count("audio_label")) {
            _audioDeviceName = "WWU SDR";
        }
        SoapySDR_logf(SOAPY_SDR_INFO, "2026SDR: detected Tayloe architecture, mode %s",
                      _johnsonMode ? "JOHNSON" : "DIRECT");
    }

    // ── Set initial sample rate ───────────────────────────────────────────
    _setParam("RATE", std::to_string((int)_sampleRate));

    // ── Set initial gain & antenna if DDC ──────────────────────────────────
    if (_isDDC) {
        _pgaCode = 0; // 0 = straight path (+40 dB nominal gain)
        _setParam("PGA", "0");
        _refMux = 0;  // 0 = SDR RF Antenna RX
        _setParam("REF", "0");
    }

    // ── Pre-allocate ring buffer ──────────────────────────────────────────
    _ring.assign(RING_FRAMES * 2, 0.0f); // *2 for I+Q per frame

    // ── Initialize miniaudio (sets up _audio) ────────────────────────────
    _setupAudio(); // defined in Streaming.cpp
}

Soapy2026SDR::~Soapy2026SDR()
{
    _teardownAudio(); // defined in Streaming.cpp
    _serial.close();
}

// ─── Identification ───────────────────────────────────────────────────────────

std::string Soapy2026SDR::getDriverKey() const { return "2026SDR"; }

std::string Soapy2026SDR::getHardwareKey() const
{
    if (_isDDC) return "Pico-Dev-iCE-DDC";
    return _johnsonAvailable ? "WWU-2026-v0.2" : "WWU-2026-v0.1";
}

SoapySDR::Kwargs Soapy2026SDR::getHardwareInfo() const
{
    SoapySDR::Kwargs info;
    info["firmware"]    = _firmwareVersion;
    info["crystal_hz"]  = std::to_string(_crystalFreq);
    info["mixer_mode"]  = _sdrMode;
    info["is_ddc"]      = _isDDC ? "yes" : "no";
    info["serial_port"] = _serialPath;
    info["audio_label"] = _audioDeviceName;
    return info;
}

// ─── Channels ────────────────────────────────────────────────────────────────

size_t Soapy2026SDR::getNumChannels(int direction) const
{
    return (direction == SOAPY_SDR_RX) ? 1 : 0;
}

// ─── Antenna ─────────────────────────────────────────────────────────────────
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

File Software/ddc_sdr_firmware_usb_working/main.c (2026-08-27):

#include <stdbool.h>
#include <stddef.h>
#include <stdint.h>
#include <stdio.h>
#include <stdlib.h>
#include <string.h>

#include "bsp/board_api.h"
#include "tusb.h"

#include "hardware/clocks.h"
#include "hardware/dma.h"
#include "hardware/gpio.h"
#include "hardware/irq.h"
#include "hardware/pio.h"
#include "hardware/spi.h"
#include "hardware/sync.h"
#include "hardware/vreg.h"
#include "pico/stdlib.h"
#include "pico/bootrom.h"

#include "boards.h"
#include "agc_control.h"
#include "ddc_protocol.h"
#include "ice_cram.h"
#include "ice_fpga.h"
#include "ice_fpga_data.h"
#include "ice_spi.h"
#include "ice_usb.h"
#include "i2s_rx.pio.h"
#include "i2s_tx.pio.h"
#ifdef DDC_HAS_STORED_RX
#include "fpga_bitstream_rx.h"
#endif
#ifdef DDC_HAS_STORED_TX
#include "fpga_bitstream_tx.h"
#endif

#define DDC_I2S_DATA_PIN 14
#define DDC_I2S_TX_PIN 13
#define DDC_I2S_BCK_PIN 15
#define DDC_I2S_WS_PIN 16
#define DDC_TR_PIN 28
#define DDC_REF_PIN 26
#define DDC_FPGA_INT_PIN 0
#define DDC_PGA_GPIO_BASE 8
#define DDC_PGA_GPIO_COUNT 4
#define DDC_DEFAULT_SAMPLE_RATE 48000u
#define DDC_RUNTIME_SPI_BAUD_HZ 10000000u
#define DDC_MAX_WORDS_PER_BUFFER 192u
#define DDC_TX_BUFFER_COUNT 4u
#define DDC_AUDIO_CAPTURE_INTERFACE 3u
#define DDC_AUDIO_PLAYBACK_INTERFACE 4u
#define DDC_LINE_BUFFER_SIZE 80u

typedef enum {
    DDC_FPGA_IMAGE_RX,
    DDC_FPGA_IMAGE_TX,
    DDC_FPGA_IMAGE_DFU,
} ddc_fpga_image_t;

typedef struct {
    const uint8_t *data;
    size_t size;
} ddc_fpga_bitstream_t;

static uint32_t audio_buffer_a[DDC_MAX_WORDS_PER_BUFFER];
static uint32_t audio_buffer_b[DDC_MAX_WORDS_PER_BUFFER];
static uint32_t tx_audio_buffers[DDC_TX_BUFFER_COUNT][DDC_MAX_WORDS_PER_BUFFER];
static uint32_t tx_silence_buffer[DDC_MAX_WORDS_PER_BUFFER];
static uint g_pio_offset;
static uint g_tx_pio_offset;
static int dma_channel_a = -1;
static int dma_channel_b = -1;
static int tx_dma_channel = -1;
static dma_channel_config_t tx_dma_config;
static volatile uint32_t words_per_buffer = 96u;
static volatile uint32_t ready_buffers;
static volatile uint32_t tx_ready_mask;
static volatile bool tx_dma_active;
static volatile bool tx_dma_silence;
static volatile uint8_t tx_dma_buffer;
static bool i2s_running;
static bool tx_running;
static bool runtime_spi_ready;
static bool fpga_ready;
static bool update_prepared;
static ddc_fpga_image_t active_fpga_image = DDC_FPGA_IMAGE_DFU;
static uint32_t sample_rate = DDC_DEFAULT_SAMPLE_RATE;
static volatile bool fpga_interrupt_pending;
static ddc_agc_state_t agc_state;

static uint8_t capture_alt;
static uint8_t playback_alt;
static uint32_t audio_requested_rate = DDC_DEFAULT_SAMPLE_RATE;
static uint8_t audio_mute[3];
static uint8_t tx_fill_buffer;
static uint32_t tx_fill_words;

static char line_buffer[DDC_LINE_BUFFER_SIZE];
static uint8_t line_length;
static bool ready_message_sent;
static uint32_t last_frequency_hz;
static uint32_t freq_cmd_count;

static bool fpga_write_command(uint8_t command, uint32_t value);

static bool fpga_get_stored_image(ddc_fpga_image_t image,
                                  ddc_fpga_bitstream_t *bitstream)
{
    if (bitstream == NULL) {
        return false;
    }

    switch (image) {
    case DDC_FPGA_IMAGE_RX:
#ifdef DDC_HAS_STORED_RX
        bitstream->data = ddc_fpga_rx_bitstream;
        bitstream->size = DDC_FPGA_RX_BITSTREAM_SIZE;
        return true;
#else
        return false;
#endif
    case DDC_FPGA_IMAGE_TX:
#ifdef DDC_HAS_STORED_TX
        bitstream->data = ddc_fpga_tx_bitstream;
        bitstream->size = DDC_FPGA_TX_BITSTREAM_SIZE;
        return true;
#else
        return false;
#endif
    default:
        return false;
    }
}

static const char *fpga_image_name(ddc_fpga_image_t image)
{
    switch (image) {
    case DDC_FPGA_IMAGE_RX:
        return "RX";
    case DDC_FPGA_IMAGE_TX:
        return "TX";
    default:
        return "DFU";
    }
}

static void tr_set_receive(bool receive)
{
    gpio_put(DDC_TR_PIN, receive ? 1u : 0u);
}

static void pga_set_code(uint8_t code)
{
    code &= DDC_PGA_MAX_CODE;
    for (uint gpio = DDC_PGA_GPIO_BASE;
         gpio < DDC_PGA_GPIO_BASE + DDC_PGA_GPIO_COUNT;
         gpio++) {
        gpio_put(gpio, (code >> (gpio - DDC_PGA_GPIO_BASE)) & 1u);
    }
}

static void fpga_interrupt_handler(uint gpio, uint32_t events)
{
    (void)gpio;
    (void)events;
    fpga_interrupt_pending = true;
}

static void handle_fpga_interrupt(void)
{
    if (!fpga_interrupt_pending || !fpga_ready || !runtime_spi_ready) {
        return;
    }

    fpga_interrupt_pending = false;
    if (ddc_agc_on_otr(&agc_state))
        pga_set_code(agc_state.pga_code);
    fpga_write_command(DDC_FPGA_CMD_CLEAR_OTR, 1u);
}

static void agc_task(void)
{
    bool fpga_int_high;
    uint64_t now_ms;

    if (!fpga_ready || update_prepared)
        return;

    fpga_int_high = gpio_get(DDC_FPGA_INT_PIN);
    now_ms = time_us_64() / 1000u;
    if (ddc_agc_tick(&agc_state, fpga_int_high, now_ms))
        pga_set_code(agc_state.pga_code);
}

static void cdc_write(const char *text)
{
    tud_cdc_write_str(text);
    tud_cdc_write_flush();
}

static void dma_handler(void)
{
    uint32_t status = dma_hw->ints0;

    if (status & (1u << dma_channel_a)) {
        dma_hw->ints0 = 1u << dma_channel_a;
        dma_channel_set_write_addr(dma_channel_a, audio_buffer_a, false);
        dma_channel_set_trans_count(dma_channel_a, words_per_buffer, false);
        ready_buffers |= 1u;
    }
    if (status & (1u << dma_channel_b)) {
        dma_hw->ints0 = 1u << dma_channel_b;
        dma_channel_set_write_addr(dma_channel_b, audio_buffer_b, false);
        dma_channel_set_trans_count(dma_channel_b, words_per_buffer, false);
        ready_buffers |= 2u;
    }
    if (tx_dma_channel >= 0 && (status & (1u << tx_dma_channel))) {
        uint32_t buffer_bit;

        dma_hw->ints0 = 1u << tx_dma_channel;
        buffer_bit = tx_dma_silence ? 0u : 1u << tx_dma_buffer;
        tx_dma_active = false;
        if (buffer_bit != 0u) {
            tx_ready_mask &= ~buffer_bit;
        }
        tx_dma_silence = false;
    }
}

static void i2s_configure(void)
{
    pio_gpio_init(pio0, DDC_I2S_DATA_PIN);
    pio_gpio_init(pio0, DDC_I2S_BCK_PIN);
    pio_gpio_init(pio0, DDC_I2S_WS_PIN);
    gpio_pull_up(DDC_I2S_DATA_PIN);
    gpio_pull_up(DDC_I2S_BCK_PIN);
    gpio_pull_up(DDC_I2S_WS_PIN);
    pio_sm_set_consecutive_pindirs(pio0, 0, DDC_I2S_DATA_PIN, 3, false);

    pio_sm_config config = i2s_rx_program_get_default_config(g_pio_offset);
    sm_config_set_in_pins(&config, DDC_I2S_DATA_PIN);
    sm_config_set_in_shift(&config, false, true, 32);
    sm_config_set_clkdiv(&config, 1.0f);
    pio_sm_init(pio0, 0, g_pio_offset, &config);
}
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

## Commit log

2026-07-18 Working on the schematic
    [AF_DAC.kicad_sch, DDC_SDR.kicad_sch, FPGA_Power.kicad_sch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]
2026-07-21 Much Schematic Progress
    [AF_DAC.kicad_sch, DDC_SDR.kicad_pcb, DDC_SDR.kicad_sch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]
2026-07-21 Fixing lots of schematic issues
    [DDC_SDR.kicad_sch, PGA.kicad_sch, filter_playground.kicad_sch]
2026-07-21 More fixes
    [DDC_SDR.kicad_sch, angle_encoder.kicad_sch]
2026-07-22 Fixed a lot more mistakes...
    [AF_DAC.kicad_sch, DDC_SDR.kicad_sch, FPGA_Power.kicad_sch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]
2026-07-22 Switching TX for VNA too
    [DDC_SDR.kicad_sch]
2026-07-22 Fixing more errors....
    [DDC_SDR.kicad_sch, FPGA_Power.kicad_sch, PGA.kicad_sch]
2026-07-22 Removed FPGA Flash
    [DDC_SDR.kicad_sch]
2026-07-22 Added provision for switch leakage current.
    [DDC_SDR.kicad_sch, PGA.kicad_sch]
2026-07-22 Minor tweaks...
    [DDC_SDR.kicad_sch, FPGA_Power.kicad_sch]
2026-07-23 Starting to place components
    [AF_DAC.kicad_sch, DDC_SDR.kicad_pcb, DDC_SDR.kicad_sch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]
2026-07-23 Working on the analog chains
    [DDC_SDR.kicad_pcb, DDC_SDR.kicad_sch, PGA.kicad_sch]
2026-07-24 AF DAC Some VDDA Placed
    [AF_DAC.kicad_sch, DDC_SDR.kicad_pcb, DDC_SDR.kicad_sch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]
2026-07-24 SMA/LogicAnalyzer and VDDA placed
    [AF_DAC.kicad_sch, DDC_SDR.kicad_pcb, DDC_SDR.kicad_sch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]
2026-07-24 FPGA 1.2V placed
    [DDC_SDR.kicad_pcb, FPGA_Power.kicad_sch]
2026-07-24 Fixed schematic errors, all placed
    [731000133.stp, AF_DAC.kicad_sch, Connecteur BNC Amphenol RF Femelle Droit.STEP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]
2026-07-25 First wiring
    [DDC_SDR.kicad_pcb, DDC_SDR.kicad_sch]
2026-07-26 Lots of signal traces wided
    [AF_DAC.kicad_sch, DDC_SDR.kicad_pcb, DDC_SDR.kicad_sch]
2026-07-26 Routed SPI lines on the top
    [DDC_SDR.kicad_pcb]
2026-07-26 PAM and LEDs
    [AF_DAC.kicad_sch, DDC_SDR.kicad_pcb, DDC_SDR.kicad_sch]
2026-07-26 Added test points
    [DDC_SDR.kicad_pcb, DDC_SDR.kicad_sch, VDDA.kicad_sch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]
2026-07-26 Added Prototype Area
    [AF_DAC.kicad_sch, DDC_SDR.kicad_pcb, DDC_SDR.kicad_sch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]
2026-07-26 Some 3D models
    [DDC_SDR.kicad_pcb, DDC_SDR.kicad_sch, Raspberry Pi Pico-R3.STEP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]
2026-07-27 Wiring slow digital signals
2026-07-27 Power supplies
    [DDC_SDR.kicad_pcb]
2026-07-27 Power Planes started
    [DDC_SDR.kicad_pcb]
2026-07-27 0 disconnects
    [AF_DAC.kicad_sch, DDC_SDR.kicad_pcb, DDC_SDR.kicad_sch]
2026-07-27 67 violations
    [DDC_SDR.kicad_pcb]
2026-07-27 0 errors 86 warnings
    [DDC_SDR.kicad_pcb]
2026-07-27 0 errors 0 warnings
    [AF_DAC.kicad_sch, DDC_SDR.kicad_pcb, DDC_SDR.kicad_sch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]
2026-07-27 Added ground planes
    [AF_DAC.kicad_sch, DDC_SDR.kicad_pcb, DDC_SDR.kicad_sch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]
2026-07-27 Fixed the gap between power zones.
    [DDC_SDR.kicad_pcb]
2026-07-28 Named it
    [DDC_SDR.kicad_pcb]
2026-07-28 Changed Readme
    [cmos_oscillator.kicad_sch]
2026-07-28 It looks changed, so committing new pico-dev-ice.
    [AF_DAC.kicad_sch, FPGA_Power.kicad_sch, PGA.kicad_sch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]
2026-07-29 Added the Filter board
    [Filter_Board.kicad_pcb, Filter_Board.kicad_sch]
2026-07-29 Added board label to filter playground
    [Filter_Board.kicad_pcb]
2026-07-29 JLCPCB Order Fixes
    [Pico-Dev-iCE.kicad_pcb, Pico-Dev-iCE.kicad_sch, VDDA.kicad_sch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]
2026-07-30 Getting ready to submit to JLCPCB.
    [AF_DAC.kicad_sch, FPGA_Power.kicad_sch, PGA.kicad_sch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]
2026-07-31 Getting ready to submit to JLCPCB
    [AF_DAC.kicad_sch, FPGA_Power.kicad_sch, PGA.kicad_sch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]
2026-08-03 Modifying the pico-ice-sdk for the Pico Dev-iCE.
    This has not been tested on the Pico Dev-iCE yet.
2026-08-04 Ignore Software/ dir to prevent KiCad symlink recursion hang
2026-08-04 Reorganize into Hardware/ and Software/ subdirectories
    [731000133.stp, AF_DAC.kicad_sch, Connecteur BNC Amphenol RF Femelle Droit.STEP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]
2026-08-04 Complete reorganization into Hardware/ and Software/ subdirectories
    [AF_DAC.kicad_sch, FPGA_Power.kicad_sch, Filter_Board.kicad_pcb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]
2026-08-05 fixed U4 ad SMA footprints
    [Pico-Dev-iCE.kicad_pcb, Pico-Dev-iCE.kicad_sch]
2026-08-25 Add native SoapySDR driver for Pico-Dev-iCE DDC SDR
2026-08-26 Fix SoapySDR DDC stream formatting, serial sync, and gain mapping for SDR++
    [Settings.cpp, quisk_conf_ddc.py]
2026-08-26 Add OpenHPSDR Protocol 1 Wi-Fi firmware and tools for Pico W
2026-08-26 Auto-initialize pico-ice-sdk submodule in build_picow.sh
2026-08-26 Improve async Wi-Fi connection and LED status in main.c
2026-08-26 Add 1200 baud touch reset and fix OpenHPSDR 24-bit sample layout
    [main.c]
2026-08-27 Fix USB SDR firmware for standard 125 MHz RP2040 operation and preserve working USB build
    [bin2header.py, ddc_sdr.pcf, dfu_fpga.py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]
2026-08-27 Add Wi-Fi OpenHPSDR Protocol 1 support for Pico W
    - Restore cooperative single-core architecture on Core 0
    - Support OpenHPSDR Protocol 1 Hermes streaming over Wi-Fi (UDP port 1024)
    - Add 1200 baud touch soft reboot for Pico W
    - Add CDC commands for WIFI and SCAN RF diagnostics
    - Align I/Q sample packing for standard SDR++ Hermes orientation
    - Add test_openhpsdr_stream.py diagnostic and stream verification tool
    - Update README documentation and LED status indicators
    [main.c, test_openhpsdr_stream.py]
2026-08-27 Add Wi-Fi OpenHPSDR inactivity watchdog and DHCP hostname
    - Add 2-second streaming inactivity watchdog in openhpsdr_task()
    - Back off UDP streaming when udp_sendto fails or buffers are exhausted
    - Set DHCP option 12 hostname to 'Pico-Dev-iCE-SDR'
    - Increase reconnect scan watchdog to 15s to prevent scan thrashing
    [main.c]
2026-08-27 Enable threadsafe background Wi-Fi and improve OpenHPSDR streaming stability
    [main.c, runner.py]
2026-08-27 Compensate for SDR++ internal I/Q swap and enable Wi-Fi power save disable on link UP
    [main.c]
2026-08-27 Fix intermittent 50% I/Q phase swap by arming DMA before enabling PIO and resetting stream indices
    [main.c]
2026-09-25 Added led_test code
2026-10-01 Support OpenHPSDR Protocol 1 Wi-Fi streaming alongside working UAC1 USB audio
    - Expanded audio ring buffer depth to 32 slots (256 words each) to prevent buffer overrun corruption
    - Fixed FPGA interrupt handler filtering to only trigger on DDC_FPGA_INT_PIN (avoiding CYW43 IRQ cross-talk)
    - Integrated non-blocking flow control and active credit polling for CYW43 Wi-Fi driver
    - Eliminated SPI contention by pausing status/LED polling during active streaming
    - Preserved UAC1 audio streaming FIFO synchronization
    - Added manage_sdr.py automation tool for build, flash, Wi-Fi wait, and telemetry diagnostics
    - Added test_openhpsdr.py test suite for discovery, throughput, and I/Q balance verification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
    [flash_picow.py, main.c, manage_sdr.py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]
2026-10-02 Added oss-cad-suite lecture
2026-10-02 modified the OSS CAD Lecture Note
2026-10-02 Fixed errors in the OSS CAD Suite Notebook
2026-10-04 WIP: save state after Cline session crash
    [bin2header.py, ddc_sdr.pcf, dfu_fpga.py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]
